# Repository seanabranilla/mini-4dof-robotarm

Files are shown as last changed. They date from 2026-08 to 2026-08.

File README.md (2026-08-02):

# mini-4dof-robotarm


**> A 3D printed mini 4-DOF robotic arm featuring a removable control unit, multi-mode teleoperation, and Inverse Kinematics control—engineered around static torque analysis.**

Overall, this project provides a cost-effective, modular platform to practice Inverse Kinematics and experiment with different robotic arm geometries without needing to rebuild the underlying control hardware.

---

## **❗IMPORTANT NOTE❗**


- this project is a PROTOTYPE, there are still some minor issues with the mechanical design and parts to be improved and are in development
- this github repo is currently under construction, only major content has been added and there may be some missing files and information.

---

## *🎯 Project Goals*
**Low-Cost Kinematic Platform:** Design and build an affordable 4-DOF mini robotic arm using budget-friendly electronics and minimal 3D printing filament.

**Universal Modular Brain:** Build a self-contained, well-built control enclosure that acts as a universal controller for future servo-based robotic arms.

**Design for Manufacturability (DFM):** Optimize CAD geometry during the design phase to minimize support structures and reduce material consumption.

**Rigorous Engineering:** Ensure all link sizing, structural decisions, and actuator choices are driven by real physical calculations rather than trial and error.

---

## 📌 Project Highlights

### 💡 Value Engineering & Hardware:
**Universal Modular Brain:** Powered by an ESP32 microcontroller paired with a PCA9685 16-channel 12-bit PWM servo driver. Offloading PWM generation to the PCA9685 allows for the brain to control robot arms with multiple servos (up to 16) that act at higher voltage (up to 12v).




**Modular Mounting System:** Uses an integrated sliding dovetail joint to quickly snap the Modular Brain into different arm bases. Dovetail sliders are isolated for easy 3D printing replacement in case of mechanical wear.

### 🛠️ Mechanical Design & DFM
**Minimal Support Printing:** Engineered the entire linkage mechanism and brain housing to lay completely flat on the build plate, requiring  minimal support material.



**Material & Weight Optimization:** Applied recessed geometry in non-critical structural areas of the brain housing to minimize filament consumption.

**Anti-Tipping Optimization:** Designed the arm base with top surface recesses and dense bottom infill to lower the overall Center of Gravity (CG) and prevent tip-over during rapid movements. Also added attachments points for legs in case of any tipping.

### 📐 Static Torque Analysis & Link Sizing



- Sized arm link lengths around the strict holding torque limits of the shoulder servo (reported **2.2 kg/cm stall torque**).
- Created a free-body diagram assuming link material density and cross-sectional areas, applying a 1.5× safety factor to servo self-weight alongside a **30g point-mass payload** at the end effector.

### 🎛️ Control & Teleoperation
The brain is designed to handle three control structures:
-  (🟢Current): Wireless teleoperation via command packets sent over Bluetooth from a custom mobile app built with MIT App Inventor.
-  (🟡In Development): Trigonometric / Vector-based Inverse Kinematics (IK) solver for direct (X, Y, Z) Cartesian positioning.
-   (🟡In Development): Waldo-Style Master Controller for direct physical teleoperation and motion tracking.

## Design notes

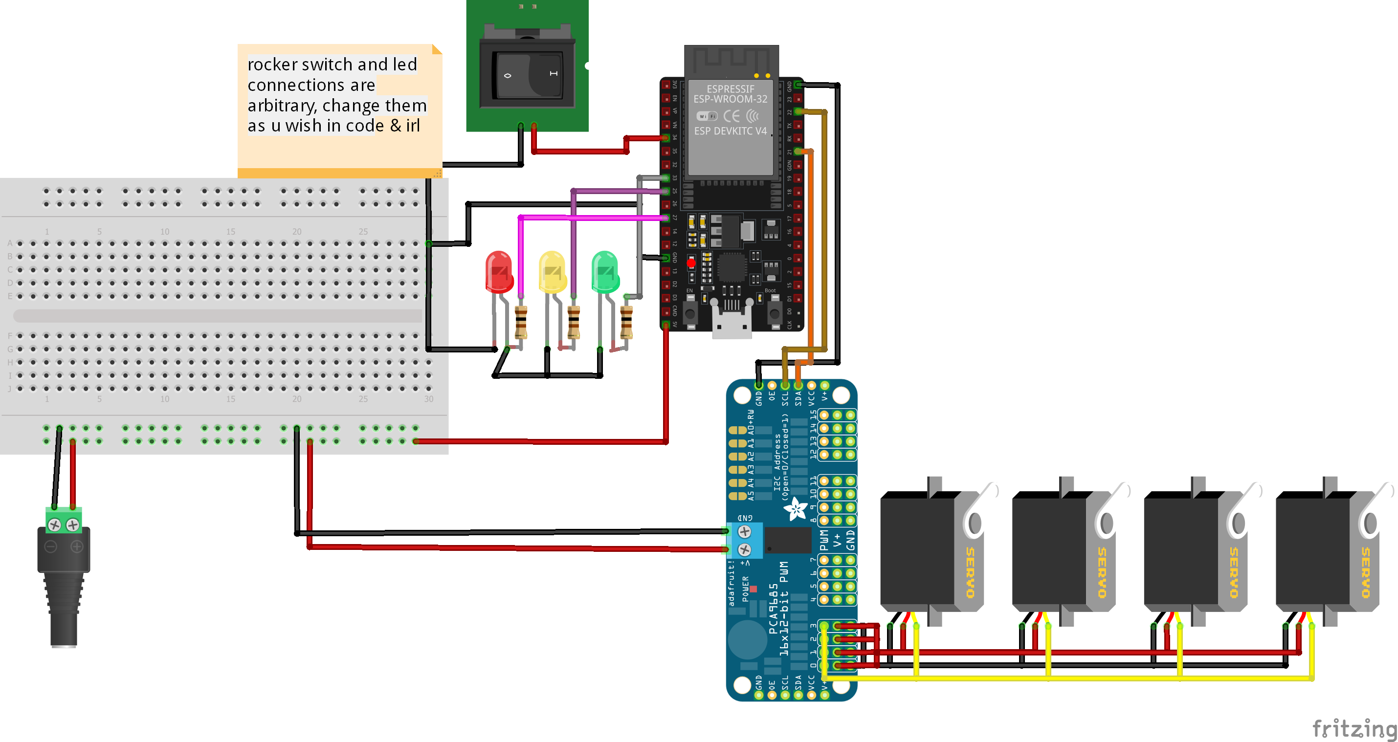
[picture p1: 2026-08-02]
hardware/circuitDiagram/RobotArm_circuitdiagram.png

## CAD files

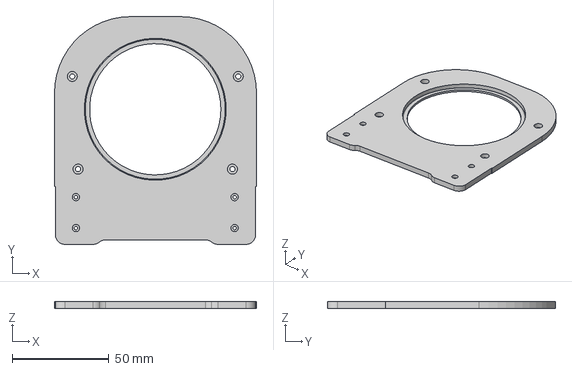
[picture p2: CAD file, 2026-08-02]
hardware/STEP/miniArm/MiniArm Cover v1.step
104.7 x 118.0 x 3.50 mm

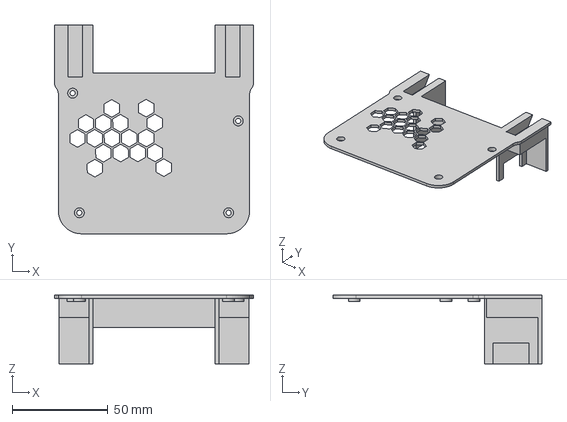
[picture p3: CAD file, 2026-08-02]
hardware/STEP/modularBrain/ModularBrain Cover v1.step
104.0 x 109.0 x 35.8 mm

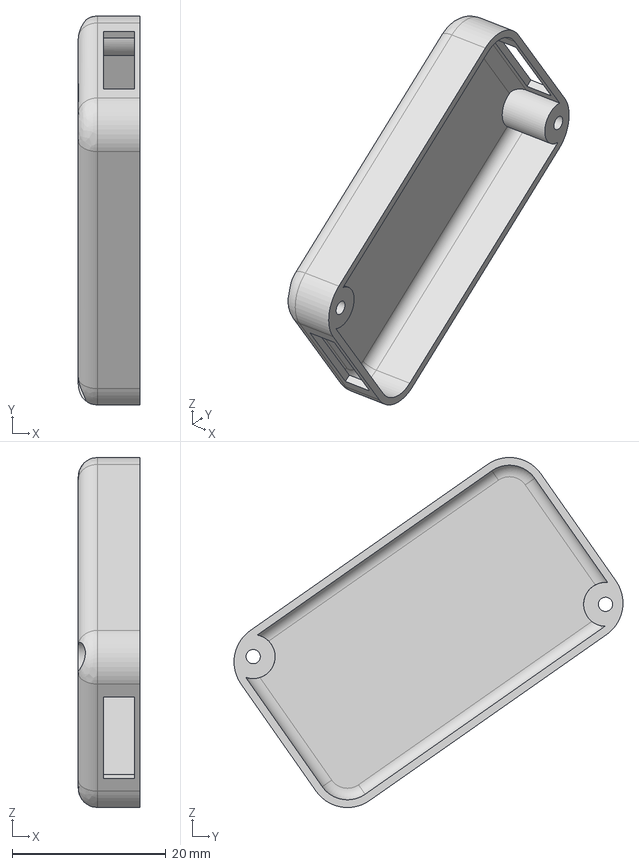
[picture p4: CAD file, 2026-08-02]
hardware/STEP/miniArm/MiniArm UpperArm Back Faceplate v1.step
8.00 x 50.6 x 45.5 mm

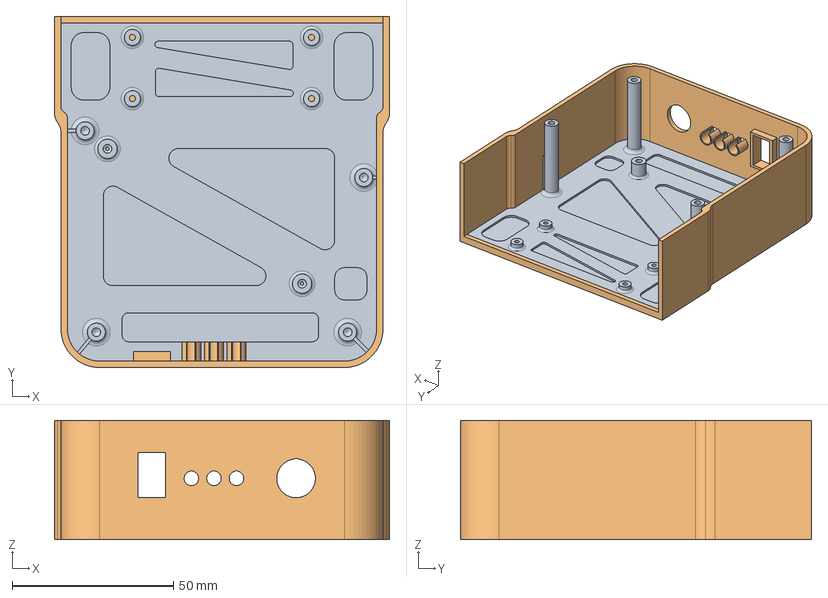
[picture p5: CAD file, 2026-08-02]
hardware/STEP/modularBrain/Modular Brain Base.step
104.0 x 109.0 x 37.0 mm

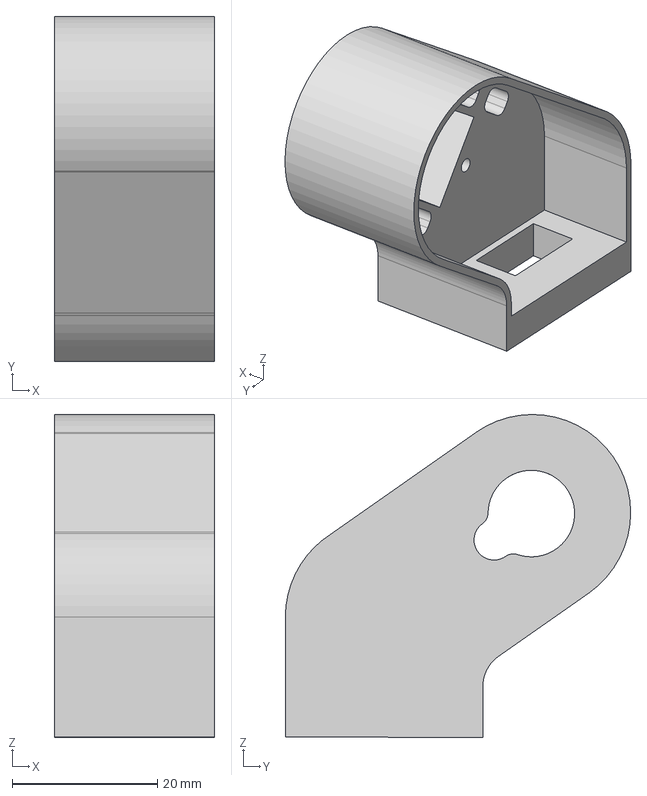
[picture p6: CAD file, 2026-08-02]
hardware/STEP/miniArm/MiniArm ShoulderHousing v1.step
22.0 x 47.5 x 44.4 mm

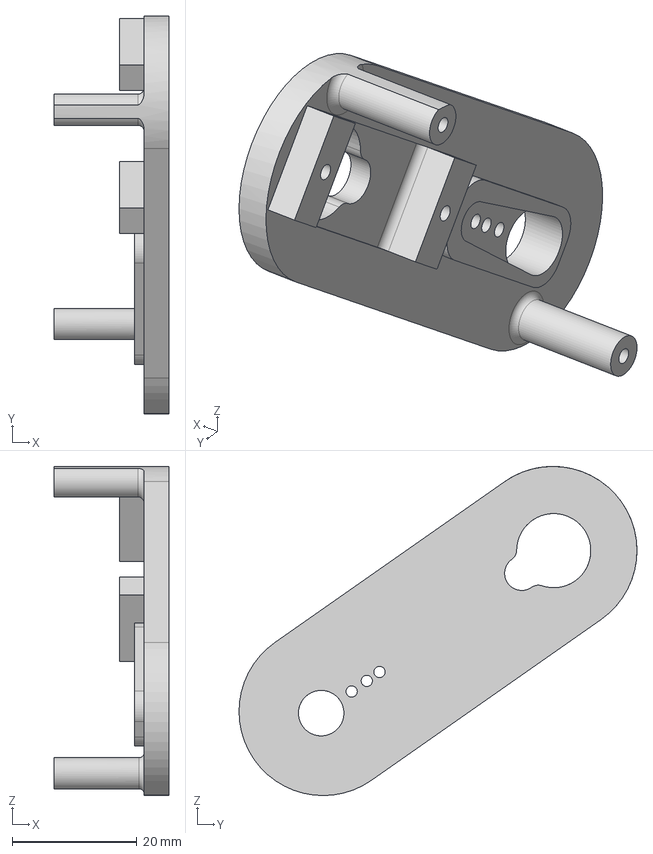
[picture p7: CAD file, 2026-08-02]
hardware/STEP/miniArm/MiniArm Forearm Link v1.step
18.4 x 63.9 x 52.8 mm

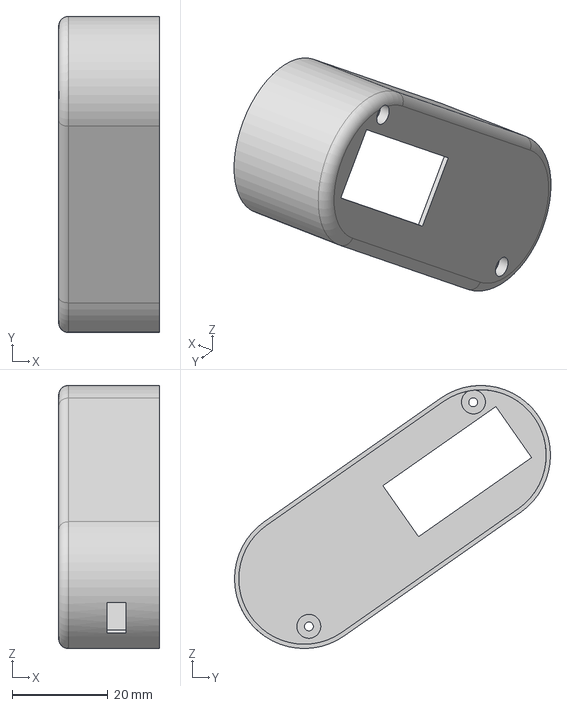
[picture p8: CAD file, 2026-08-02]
hardware/STEP/miniArm/MiniArm Forearm Fairing v1.step
21.0 x 66.0 x 54.9 mm

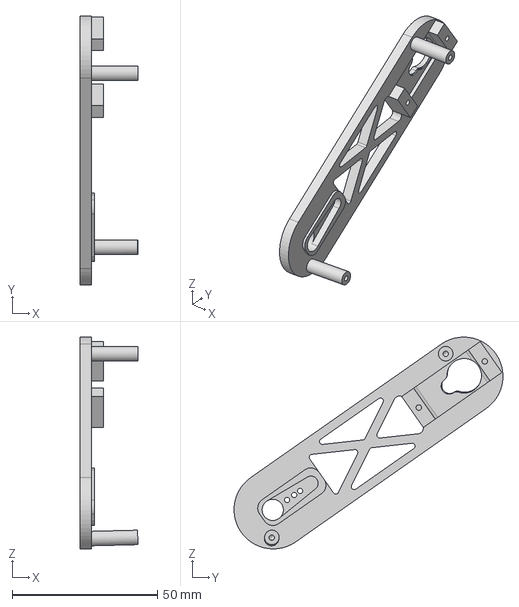
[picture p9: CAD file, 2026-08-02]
hardware/STEP/miniArm/MiniArm UpperArm Link v1.step
19.9 x 92.5 x 72.9 mm

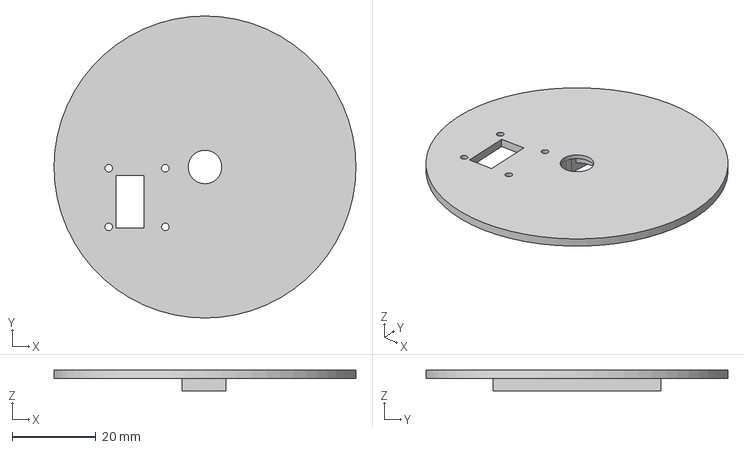
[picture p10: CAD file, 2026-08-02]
hardware/STEP/miniArm/MniArm- BaseLid v1.step
72.0 x 72.0 x 5.00 mm

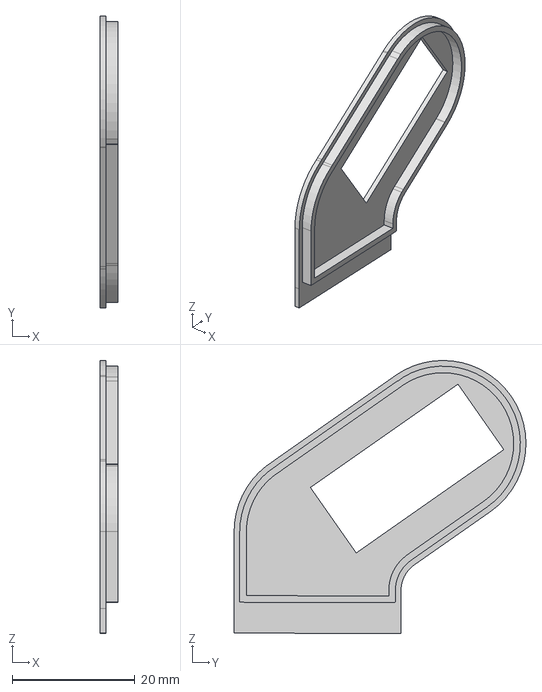
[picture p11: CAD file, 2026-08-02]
hardware/STEP/miniArm/MiniArm Shoulder Housing Facepate v1.step
3.00 x 47.5 x 44.4 mm

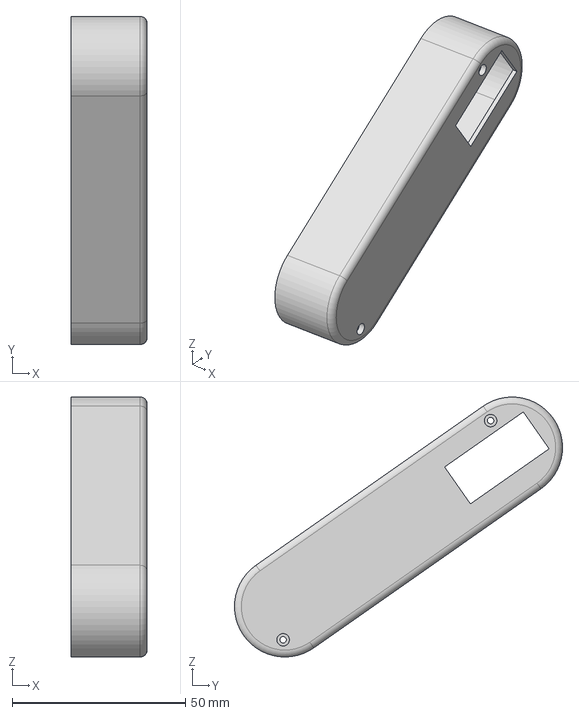
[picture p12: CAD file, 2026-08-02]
hardware/STEP/miniArm/MiniArm UpperArm Fairing (FIXED) v1.step
22.0 x 94.6 x 75.0 mm

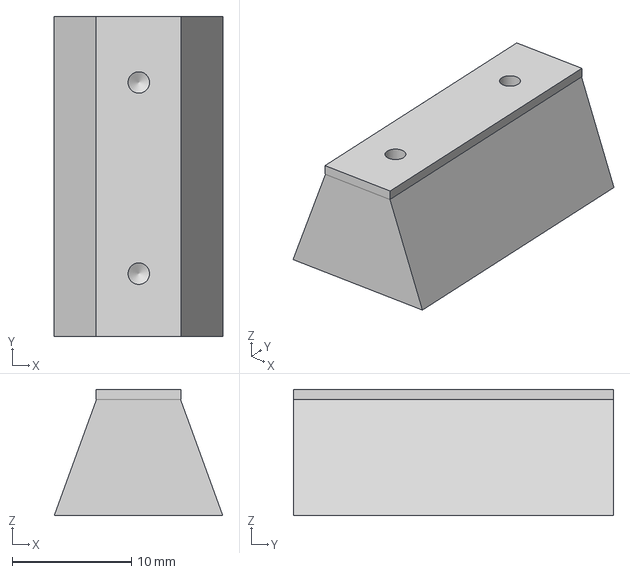
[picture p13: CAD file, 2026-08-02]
hardware/STEP/miniArm/Dovetail Attachment v1.step
14.1 x 26.8 x 10.6 mm

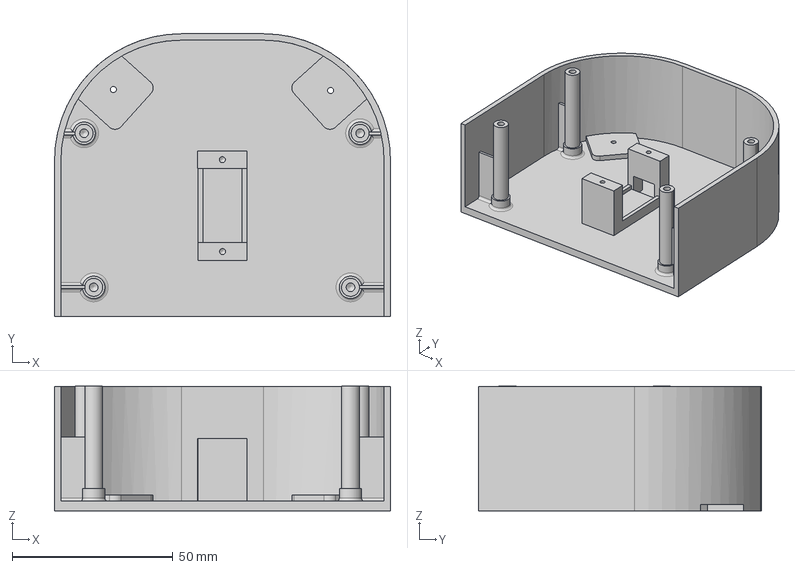
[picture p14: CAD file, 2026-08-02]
hardware/STEP/miniArm/MiniArm Base v1.step
104.7 x 88.0 x 38.9 mm

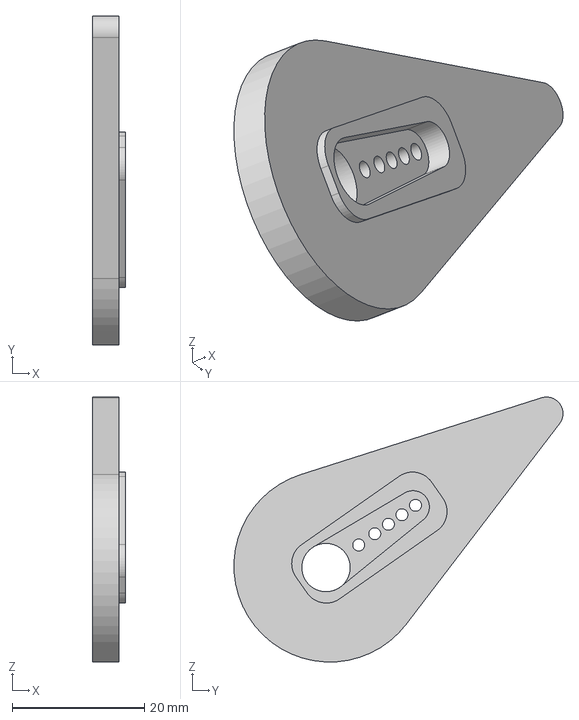
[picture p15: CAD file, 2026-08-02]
hardware/STEP/miniArm/MiniArm Pointer v1.step
5.00 x 49.7 x 40.0 mm

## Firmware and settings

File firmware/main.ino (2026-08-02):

#include "BluetoothSerial.h"
#include <Wire.h>
#include <Adafruit_PWMServoDriver.h>

BluetoothSerial SerialBT;

#if !defined(CONFIG_BT_ENABLED) || !defined(CONFIG_BLUEDROID_ENABLED)
#error Bluetooth is not enabled! Please run `make menuconfig` to enable it
#endif


Adafruit_PWMServoDriver pwm = Adafruit_PWMServoDriver();
#define SERVOMIN  500 
#define SERVOMAX  2600 
const int blinkPin = 27;
const int mode1Pin = 25;


int currentPosW = 180;
int currentPosE = 180;
int currentPosS = 60;
int currentPosB = 90;

int targetPosW = 180;
int targetPosE = 180;
int targetPosS = 60;
int targetPosB = 90;

const int stepDelay = 10;  //10ms delay/step
unsigned long lastUpdateTime = 0;




void moveServoE(int servoID, int angle){       //moves the elbow in 0 to 180 deg
  angle = constrain(angle, 0, 180);
  int pulse = map(angle, 0, 180, SERVOMIN, SERVOMAX);
  pwm.writeMicroseconds(servoID, pulse);

}

void moveServoB(int servoID, int angle){       //moves the base 
  angle = constrain(angle, 0, 180);
  int pulse = map(angle, 0, 180, 2500, SERVOMIN);
  pwm.writeMicroseconds(servoID, pulse);

}

void moveServoW(int servoID, int angle){    //movrs the wrist 0 deg to 180 deg
  angle = constrain(angle, 0, 180);
  int pulse = map(angle, 0, 180, SERVOMAX, SERVOMIN);
  pwm.writeMicroseconds(servoID, pulse);
}

void moveServoS(int servoID, int angle){  //moves shoulder servo with limitations
  angle = constrain(angle, 60, 180);
  int pulse = map(angle, 60, 180, 2500, 1200);

  
  pwm.writeMicroseconds(servoID, pulse);
  
}

void signalBlink(){
  static unsigned long blinkTime = 0;
  static bool ledState = LOW;
  int blinkDelay = 500;
  if (millis()-blinkTime >= blinkDelay){
    blinkTime = millis();
    ledState != ledState;

    digitalWrite(blinkPin, ledState);
    
  }
  
  
}



void setup() {
  // put your setup code here, to run once:
  Serial.begin(115200);
  SerialBT.begin("ESP32_Robot_Arm");
  pinMode(blinkPin, OUTPUT);
  pinMode(mode1Pin, OUTPUT);


  pwm.begin();

  pwm.setPWMFreq(50); //set at 50hz
  
  
  moveServoW(3, 180);  // Wrist
  delay(1000);
  moveServoE(2, 180);  // Elbow
  delay(1000);
  moveServoS(1, 60);  // Shoulder 
  delay(1000);
  moveServoB(0, 90);  // Base
  delay(100);
}
 

void loop() {
  digitalWrite(mode1Pin, HIGH);
  signalBlink();
 

  
  if (SerialBT.available()) {
    
    char prefix = SerialBT.read(); 
    int angle = SerialBT.parseInt(); 


    Serial.print("Received Prefix: ");
    Serial.print(prefix);
    Serial.print(" | Received Angle: ");
    Serial.println(angle);
    
    switch(prefix) {
      case 'B': // Base (Servo 0)
        targetPosB = angle;
        break;
        
      case 'S': // Shoulder (Servo 1)
        targetPosS = angle;
        break;
        
      case 'E': // Elbow (Servo 2)
        targetPosE = angle;
        break;
        
      case 'W': // Wrist/Gripper (Servo 3)
        targetPosW = angle;
        break;
        
      default:
        // Clear buffer if junk data arrives
        while(SerialBT.available() && SerialBT.read() != '\n');
        break;
    }
  }


  if (millis()-lastUpdateTime >= stepDelay){
    lastUpdateTime = millis();

    if (currentPosB != targetPosB){
      currentPosB += (targetPosB > currentPosB) ? 1 : -1;
      moveServoB(0,currentPosB);
    }

    if (currentPosS != targetPosS){
      currentPosS += (targetPosS > currentPosS) ? 1 : -1;
      moveServoS(1,currentPosS);
    }

    if (currentPosE != targetPosE){
      currentPosE += (targetPosE > currentPosE) ? 1 : -1;
      moveServoE(2,currentPosE);
    }

    if (currentPosW != targetPosW){
      currentPosW += (targetPosW > currentPosW) ? 1 : -1;
      moveServoW(3,currentPosW);
    }

    
  }
}

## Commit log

2026-08-02 Create BOM
2026-08-02 Create Mini Arm
2026-08-02 Update BOM
